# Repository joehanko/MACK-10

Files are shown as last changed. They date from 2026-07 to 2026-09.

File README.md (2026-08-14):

# MACK-10 Tensile Tester

> An open-source desktop tensile tester for affordable material characterization and education.

<p align="center">
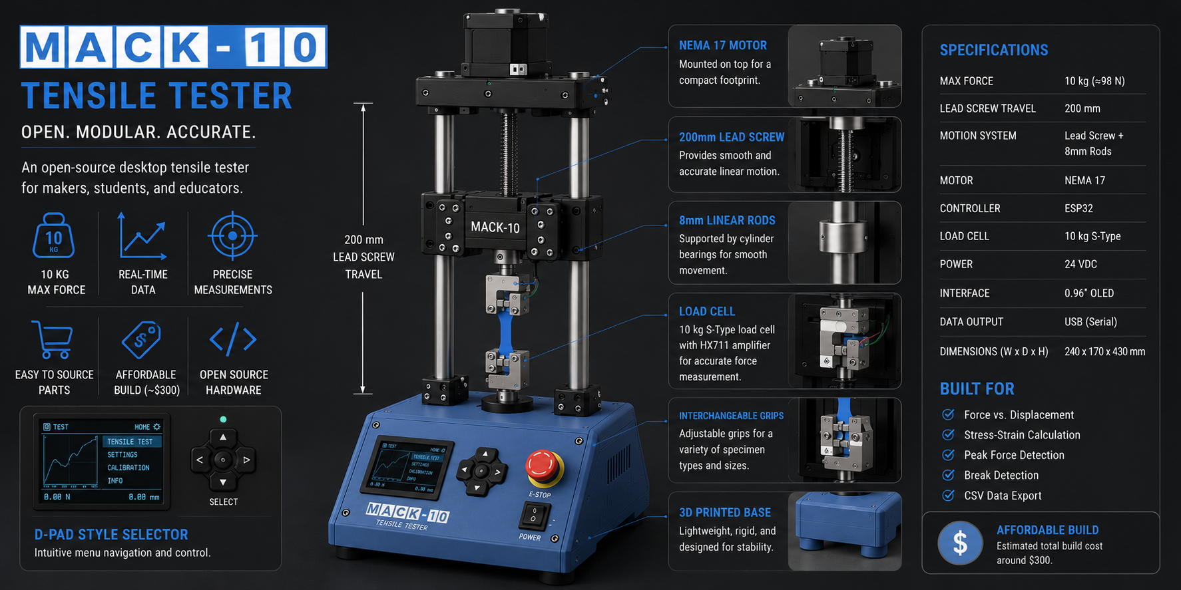
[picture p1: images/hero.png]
MACK-10 Banner
  
</p>






---

# Overview

MACK-10 is an open-source desktop tensile tester designed to measure the force and displacement of small material specimens.

The project combines an ESP32-based controller, load cell, stepper-driven linear stage, custom PCB, and 3D-printed components to create a low-cost alternative to commercial material testing equipment.

The target capacity is **10 kg (~98 N)**, making MACK-10 suitable for testing:

- 3D-printed plastics
- Engineering polymers
- Composites
- Thin metals
- Educational material samples

---

# Current Status

🚧 **Prototype Development — Revision 1**

<p align="center">
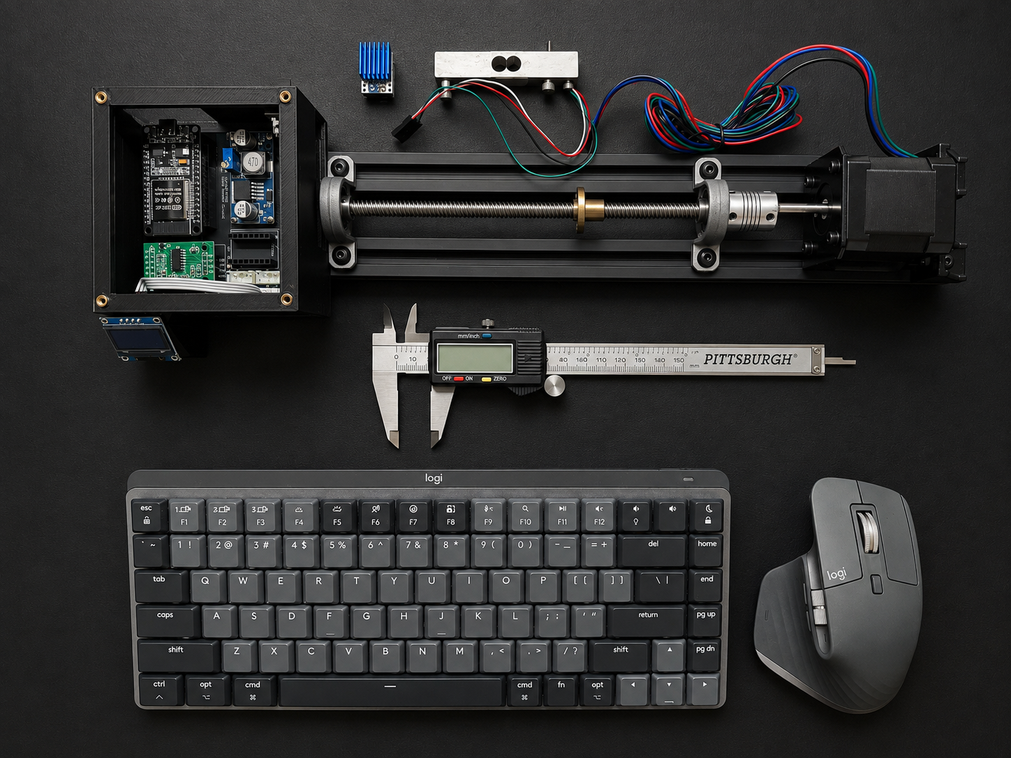
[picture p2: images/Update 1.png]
  
</p>

## Electronics

<p align="center">
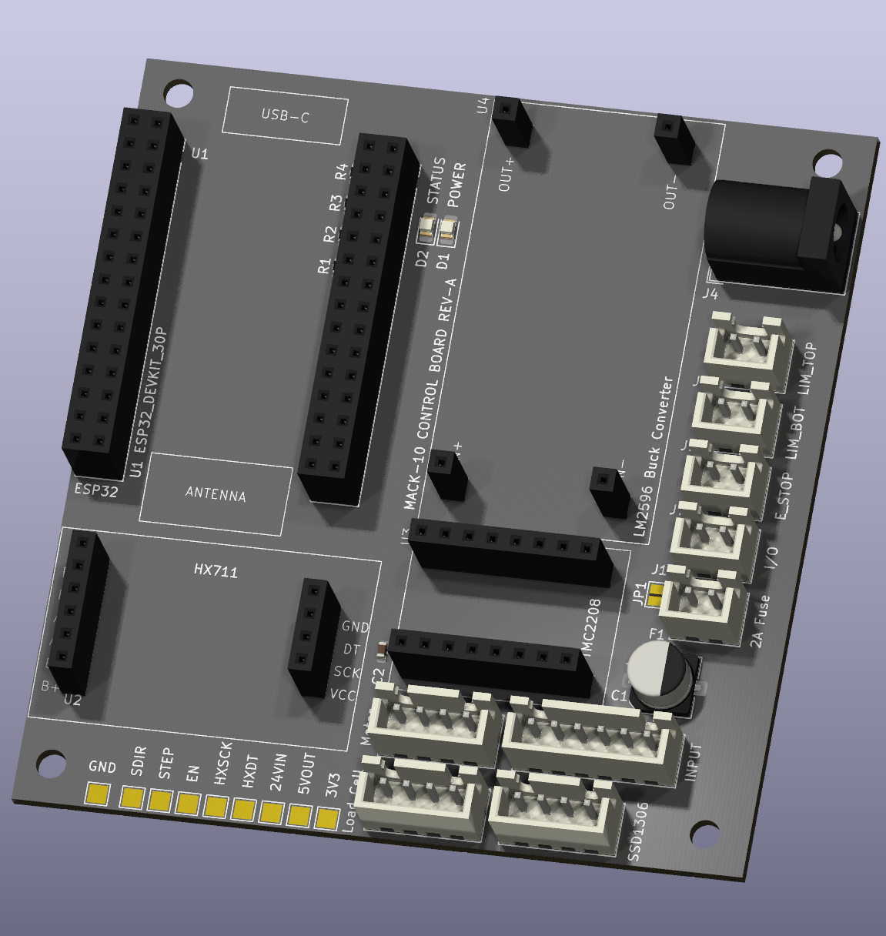
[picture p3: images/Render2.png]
MACK-10 PCB Render
  
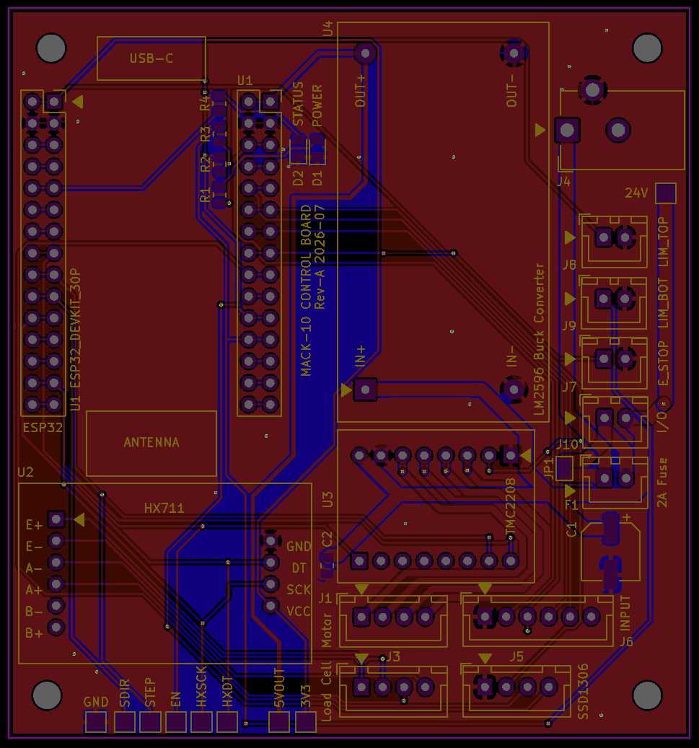
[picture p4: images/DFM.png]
MACK-10 PCB
  
</p>

- [x] Custom KiCad controller PCB
- [x] ESP32 controller
- [x] HX711 load cell interface
- [x] TMC2208 stepper driver
- [x] LM2596 power regulation
- [x] OLED interface
- [x] E-stop input
- [x] Dual limit switch inputs
- [x] PlatformIO firmware
- [x] Automatic taring
- [x] Peak force tracking
- [x] Break detection
- [x] Live serial plotting

## Mechanical

- [x] 200 mm T6×1 linear motion stage
- [x] NEMA 11 stepper drive
- [ ] Structural frame
- [ ] Load cell mount
- [ ] Specimen grips
- [ ] Electronics enclosure

## In Development

- [ ] Load cell calibration
- [ ] Crosshead speed control
- [ ] Position tracking
- [ ] Force-displacement logging
- [ ] Stress-strain calculations
- [ ] CSV export

---

# Target Specifications

| Specification  | Target |
| --- | --- |
| Maximum Force  | 10 kg (~98 N) |
| Load Cell | 10 kg S-Type |
| Controller | ESP32 |
| Motion | NEMA 11 + T6×1 Lead Screw |
| Travel | 200 mm |
| User Interface | 128×64 OLED |
| PCB | Custom KiCad Design |
| Firmware | PlatformIO |

---

# Bill of Materials

## Electronics

| Qty | Component | Approx. Cost | Line Total |
| ----: | --- | ---: | ---: |
| 1 | ESP32 DevKit V1 | $8.00 | $8.00 |
| 1 | Custom MACK-10 Controller PCB | $1.08 | $1.08 |
| 1 | HX711 Load Cell Amplifier | $3.00 | $3.00 |
| 1 | TMC2208 Stepper Driver | $5.00 | $5.00 |
| 1 | LM2596 Buck Converter | $2.00 | $2.00 |
| 1 | 10 kg S-Type Load Cell | $25.00 | $25.00 |
| 1 | SSD1306 128×64 OLED | $5.00 | $5.00 |
| 1 | PCB Fuse Holder | $1.00 | $1.00 |
| 1 | 2–2.5 A Fuse | $0.50 | $0.50 |
| 1 | Power Switch | $3.00 | $3.00 |
| 1 | Emergency Stop Switch | $12.00 | $12.00 |
| 2 | Limit Switches | $2.00 | $4.00 |
| 1 Set | JST-XH Connectors & Crimps | $4.00 | $4.00 |
| 1 Set | Female Header Sockets | $2.00 | $2.00 |
| — | LEDs, Resistors & Capacitors  | ~$2.00 | ~$2.00 |
| — | Wire, Heat Shrink & Misc. | ~$5.00 | ~$5.00 |

**Estimated Electronics Cost: ~$83**

## Mechanical

| Qty | Component | Approx. Cost | Line Total |
| --: | --- | ---: | ---: |
| 1 | T6×1 Linear Motion Stage, 200 mm | $31.99 | $31.99 |
| 1 | NEMA 11 Stepper Motor | Included | Included |
| 1 | T6×1 Lead Screw | Included | Included |
| 1 | Linear Guide & Carriage | Included | Included |
| 1 | Structural Frame Hardware | ~$20.00 | ~$20.00 |
| 1 | Grip Hardware | ~$20.00 | ~$20.00 |
| 1 | M3 Fastener Kit | ~$10.00 | ~$10.00 |
| 1 | M3 Heat-Set Inserts | ~$5.00 | ~$5.00 |
| — | Filament | ~$20.00 | ~$20.00 |

**Estimated Mechanical Cost: ~$107**

**Current Estimated Build Cost: ~$190 + power supply and miscellaneous hardware**

---

<p align="center">
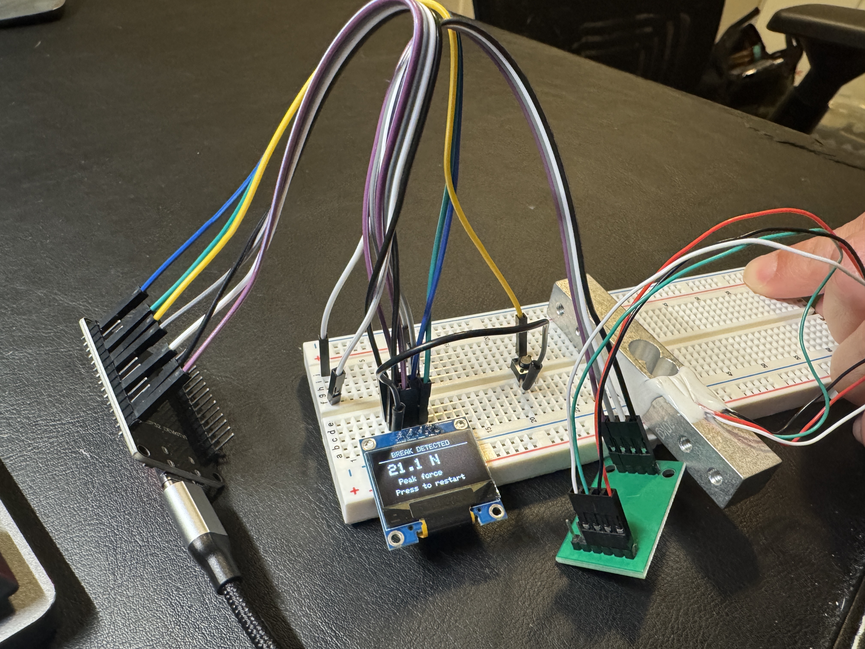
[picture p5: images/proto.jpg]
  
</p>

---

# Repository Structure

```text
firmware/    ESP32 firmware
pcb/         KiCad project files
cad/         Mechanical CAD models
docs/        Documentation
images/      Project photos and diagrams
```

---

# Roadmap

### Revision 1

Complete the mechanical assembly, calibrate the load cell, and perform initial tensile tests.

### Revision 2

Optimize the PCB, wiring, enclosure, motion control, and data acquisition.

### Revision 3

Add automated testing, material property calculations, and desktop software.

---

# Disclaimer

MACK-10 is intended for educational and hobby use and is not a replacement for calibrated or certified laboratory testing equipment.

Measurements should not be used for engineering certification, regulatory compliance, or safety-critical design decisions.

---

**Project Status:** Active Development 🚧

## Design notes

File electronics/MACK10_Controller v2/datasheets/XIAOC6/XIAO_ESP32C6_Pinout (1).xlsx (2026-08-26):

Table 7-2. QFN32 Package Pin Summary
管脚 序号 | 管脚 名称 | 管脚 类型 | 供电 管脚 | 管脚配置 |  | 模拟功能 |  | LP IO MUX 功能 |  | IO MUX 功能 |  |  |  |  |  |  | JTAG | USB | USER LED | LP IO MUX | BOOT
 |  |  |  | 复位时 | 复位后 | 0 | 1 | 0 | 1 | 0 | 类型 | 1 | 类型 | 2 | 类型 |  | GPIO | SDIO | Digital | Analog | IIC
1 | ANT | Analog |  |  |  |  |  |  |  |  |  |  |  |  |  |  | UART | SPI | ALL PWM | ALL I2S
2 | VDDA3P3 | Power
3 | VDDA3P3 | Power
4 | CHIP_PU | Analog |  |  |  |  |  |  |  |  |  |  |  |  |  |  | definition foot | multiplex
5 | VDDPST1 | Power
6 | XTAL_32K_P | IO | VDDPST1 |  |  | XTAL_32K_P | ADC1_CH0 | LP_GPIO0 | LP_UART_DTRN | GPIO0 | I/O/T | GPIO0 | I/O/T |  |  |  | D0 | A0 | GPIO0 | LP_GPIO0 | LP_UART_DTRN
7 | XTAL_32K_N | IO | VDDPST1 |  |  | XTAL_32K_N | ADC1_CH1 | LP_GPIO1 | LP_UART_DSRN | GPIO1 | I/O/T | GPIO1 | I/O/T |  |  |  | D1 | A1 | GPIO1 | LP_GPIO1 | LP_UART_DSRN
8 | GPIO2 | IO | VDDPST1 | IE | IE |  | ADC1_CH2 | LP_GPIO2 | LP_UART_RTSN | GPIO2 | I/O/T | GPIO2 | I/O/T | FSPIQ | I1/O/T |  | D2 | A2 | GPIO2 | LP_GPIO2 | LP_UART_RTSN
9 | GPIO3 | IO | VDDPST1 | IE | IE |  | ADC1_CH3 | LP_GPIO3 | LP_UART_CTSN | GPIO3 | I/O/T | GPIO3 | I/O/T |  |  |  | D11 | A3 | GPIO3 | LP_GPIO3 | LP_UART_CTSN
10 | MTMS | IO | VDDPST1 | IE | IE |  | ADC1_CH4 | LP_GPIO4 | LP_UART_RXD | MTMS | I1 | GPIO4 | I/O/T | FSPIHD | I1/O/T |  | MTMS | A4 | GPIO4 | LP_GPIO4 | LP_UART_RXD
11 | MTDI | IO | VDDPST1 | IE | IE |  | ADC1_CH5 | LP_GPIO5 | LP_UART_TXD | MTDI | I1 | GPIO5 | I/O/T | FSPIWP | I1/O/T |  | MTDI | A5 | GPIO5 | LP_GPIO5 | LP_UART_TXD
12 | MTCK | IO | VDDPST1 |  | IE, WPU |  | ADC1_CH6 | LP_GPIO6 | LP_I2C_SDA | MTCK | I1 | GPIO6 | I/O/T | FSPICLK | I1/O/T |  | MTCK | A6 | GPIO6 | LP_GPIO6 | LP_I2C_SDA
13 | MTDO | IO | VDDPST1 |  | IE |  |  | LP_GPIO7 | LP_I2C_SCL | MTDO | O/T | GPIO7 | I/O/T | FSPID | I1/O/T |  | MTDO |  | GPIO7 | LP_GPIO7 | LP_I2C_SCL
14 | GPIO8 | IO | VDDPST2 | IE | IE |  |  |  |  | GPIO8 | I/O/T | GPIO8 | I/O/T
15 | GPIO9 | IO | VDDPST2 | IE, WPU | IE, WPU |  |  |  |  | GPIO9 | I/O/T | GPIO9 | I/O/T |  |  |  | BOOT
16 | GPIO12 | IO | VDDPST2 |  | IE | USB_D- |  |  |  | GPIO12 | I/O/T | GPIO12 | I/O/T |  |  |  | USB_D-
17 | GPIO13 | IO | VDDPST2 |  | IE, WPU | USB_D+ |  |  |  | GPIO13 | I/O/T | GPIO13 | I/O/T |  |  |  | USB_D+
18 | GPIO14 | IO | VDDPST2 |  | IE |  |  |  |  | GPIO14 | I/O/T | GPIO14 | I/O/T |  |  |  | RF Switch
19 | GPIO15 | IO | VDDPST2 | IE | IE |  |  |  |  | GPIO15 | I/O/T | GPIO15 | I/O/T |  |  |  | USER LED
20 | VDDPST2 | Power
21 | U0TXD | IO | VDDPST2 |  | WPU |  |  |  |  | U0TXD | O | GPIO16 | I/O/T | FSPICS0 | I1/O/T |  | D6 | TX | GPIO16
22 | U0RXD | IO | VDDPST2 |  | IE, WPU |  |  |  |  | U0RXD | I1 | GPIO17 | I/O/T | FSPICS1 | O/T |  | D7 | RX | GPIO17
23 | SDIO_CMD | IO | VDDPST2 | WPU | IE |  |  |  |  | SDIO_CMD | I1/O/T | GPIO18 | I/O/T | FSPICS2 | O/T |  | D10 | MOSI | GPIO18 | SDIO_CMD
24 | SDIO_CLK | IO | VDDPST2 | WPU | IE |  |  |  |  | SDIO_CLK | I1 | GPIO19 | I/O/T | FSPICS3 | O/T |  | D8 | SCK | GPIO19 | SDIO_CLK
25 | SDIO_DATA0 | IO | VDDPST2 | WPU | IE |  |  |  |  | SDIO_DATA0 | I1/O/T | GPIO20 | I/O/T | FSPICS4 | O/T |  | D9 | MISO | GPIO20 | SDIO_DATA0
26 | SDIO_DATA1 | IO | VDDPST2 | WPU | IE |  |  |  |  | SDIO_DATA1 | I1/O/T | GPIO21 | I/O/T | FSPICS5 | O/T |  | D3 |  | GPIO21 | SDIO_DATA1
27 | SDIO_DATA2 | IO | VDDPST2 | WPU | IE |  |  |  |  | SDIO_DATA2 | I1/O/T | GPIO22 | I/O/T |  |  |  | D4 | SDA | GPIO22 | SDIO_DATA2
28 | SDIO_DATA3 | IO | VDDPST2 | WPU | IE |  |  |  |  | SDIO_DATA3 | I1/O/T | GPIO23 | I/O/T |  |  |  | D5 | SCL | GPIO23 | SDIO_DATA3
29 | VDDA1 | Power
30 | XTAL_N | Analog
31 | XTAL_P | Analog
32 | VDDA2 | Power
33 | GND | Power
ESP32C6FN4-QFN32 Package Pinout Overview
管脚 序号 | 管脚 名称 | 管脚 类型 1 | 供电 管脚 3-5 | 管脚配置 6,7 |  | 管脚功能 1,2
 |  |  |  | 复位时 | 复位后 | IO MUX | LP IO MUX | 模拟
1 | ANT | 模拟
2 | VDDA3P3 | 电源
3 | VDDA3P3 | 电源 |  |  |  |  |  |  | Table 2-4. QFN32 IO MUX Pin Functions
4 | CHIP_PU | 模拟 | VDDPST1 |  |  |  |  |  | 管脚 序号 | IO MUX / GPIO 名称 | IO MUX 功能
5 | VDDPST1 | 电源 |  |  |  |  |  |  |  |  | 0 | 类型 | 1 | 类型 | 2 | 类型
6 | XTAL_32K_P | IO | VDDPST1 |  |  | IO MUX | LP IO MUX | Analog | 6 | GPIO0 | GPIO0 | I/O/T | GPIO0 | I/O/T
7 | XTAL_32K_N | IO | VDDPST1 |  |  | IO MUX | LP IO MUX | Analog | 7 | GPIO1 | GPIO1 | I/O/T | GPIO1 | I/O/T
8 | GPIO2 | IO | VDDPST1 | IE | IE | IO MUX | LP IO MUX | Analog | 8 | GPIO2 | GPIO2 | I/O/T | GPIO2 | I/O/T | FSPIQ | I1/O/T
9 | GPIO3 | IO | VDDPST1 | IE | IE | IO MUX | LP IO MUX | Analog | 9 | GPIO3 | GPIO3 | I/O/T | GPIO3 | I/O/T
10 | MTMS | IO | VDDPST1 | IE | IE | IO MUX | LP IO MUX | Analog | 10 | GPIO4 | MTMS | I1 | GPIO4 | I/O/T | FSPIHD | I1/O/T
11 | MTDI | IO | VDDPST1 | IE | IE | IO MUX | LP IO MUX | Analog | 11 | GPIO5 | MTDI | I1 | GPIO5 | I/O/T | FSPIWP | I1/O/T
12 | MTCK | IO | VDDPST1 |  | IE, WPU 6 | IO MUX | LP IO MUX | Analog | 12 | GPIO6 | MTCK | I1 | GPIO6 | I/O/T | FSPICLK | I1/O/T
13 | MTDO | IO | VDDPST1 |  | IE | IO MUX | LP IO MUX |  | 13 | GPIO7 | MTDO | O/T | GPIO7 | I/O/T | FSPID | I1/O/T
14 | GPIO8 | IO | VDDPST2 | IE | IE | IO MUX |  |  | 14 | GPIO8 | GPIO8 | I/O/T | GPIO8 | I/O/T
15 | GPIO9 | IO | VDDPST2 | IE, WPU | IE, WPU | IO MUX |  |  | 15 | GPIO9 | GPIO9 | I/O/T | GPIO9 | I/O/T
16 | GPIO12 | IO | VDDPST2 |  | IE | IO MUX |  | Analog | 16 | GPIO12 | GPIO12 | I/O/T | GPIO12 | I/O/T
17 | GPIO13 | IO | VDDPST2 | USB_PU | IE, USB_PU | IO MUX |  | Analog | 17 | GPIO13 | GPIO13 | I/O/T | GPIO13 | I/O/T
18 | GPIO14 | IO | VDDPST2 |  | IE | IO MUX |  |  | 18 | GPIO14 | GPIO14 | I/O/T | GPIO14 | I/O/T
19 | GPIO15 | IO | VDDPST2 | IE | IE | IO MUX |  |  | 19 | GPIO15 | GPIO15 5b | I/O/T | GPIO15 | I/O/T
20 | VDDPST2 | 电源
21 | U0TXD | IO | VDDPST2 |  | WPU 7 | IO MUX |  |  | 21 | GPIO16 | U0TXD | O | GPIO16 | I/O/T | FSPICS0 | I1/O/T
22 | U0RXD | IO | VDDPST2 |  | IE, WPU | IO MUX |  |  | 22 | GPIO17 | U0RXD | I1 | GPIO17 | I/O/T | FSPICS1 | O/T
23 | SDIO_CMD | IO | VDDPST2 | WPU | IE | IO MUX |  |  | 23 | GPIO18 | SDIO_CMD | I1/O/T | GPIO18 | I/O/T | FSPICS2 | O/T
24 | SDIO_CLK | IO | VDDPST2 | WPU | IE | IO MUX |  |  | 24 | GPIO19 | SDIO_CLK | I1 | GPIO19 | I/O/T | FSPICS3 | O/T
25 | SDIO_DATA0 | IO | VDDPST2 | WPU | IE | IO MUX |  |  | 25 | GPIO20 | SDIO_DATA0 | I1/O/T | GPIO20 | I/O/T | FSPICS4 | O/T
26 | SDIO_DATA1 | IO | VDDPST2 | WPU | IE | IO MUX |  |  | 26 | GPIO21 | SDIO_DATA1 | I1/O/T | GPIO21 | I/O/T | FSPICS5 | O/T
27 | SDIO_DATA2 | IO | VDDPST2 | WPU | IE | IO MUX |  |  | 27 | GPIO22 | SDIO_DATA2 | I1/O/T | GPIO22 | I/O/T
28 | SDIO_DATA3 | IO | VDDPST2 | WPU | IE | IO MUX |  |  | 28 | GPIO23 | SDIO_DATA3 | I1/O/T | GPIO23 | I/O/T
29 | VDDA1 | 电源
30 | XTAL_N | 模拟
31 | XTAL_P | 模拟
32 | VDDA2 | 电源
33 | GND | 电源

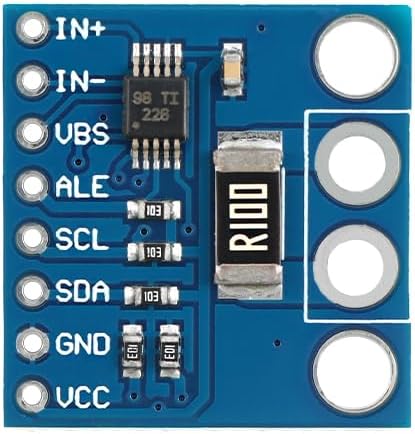
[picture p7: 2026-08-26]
electronics/MACK10_Controller v2/datasheets/INA226/51yJgzm+eNL._AC_SX679_.jpg

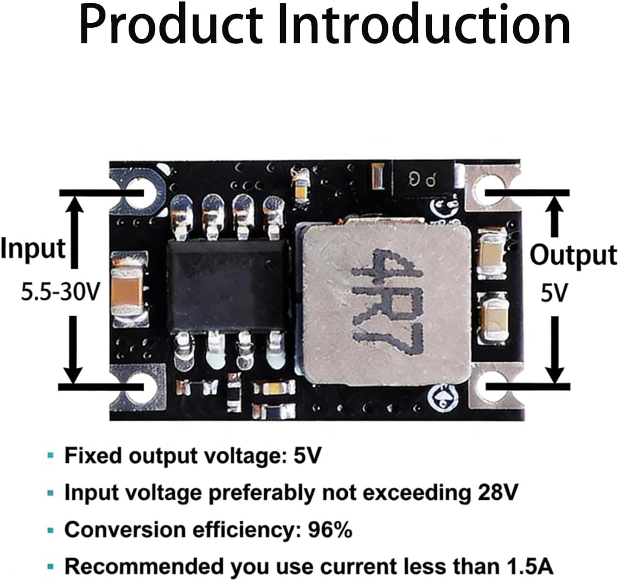
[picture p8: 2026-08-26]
electronics/MACK10_Controller v2/datasheets/Mini360/61MHXfFIcaL._AC_SL1200_.jpg

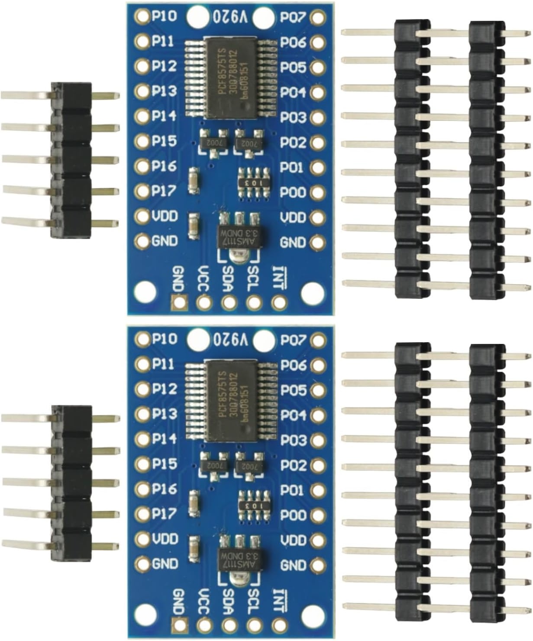
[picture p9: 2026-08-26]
electronics/MACK10_Controller v2/datasheets/PCF8575/71X1JMmVFlL._AC_SL1500_.jpg

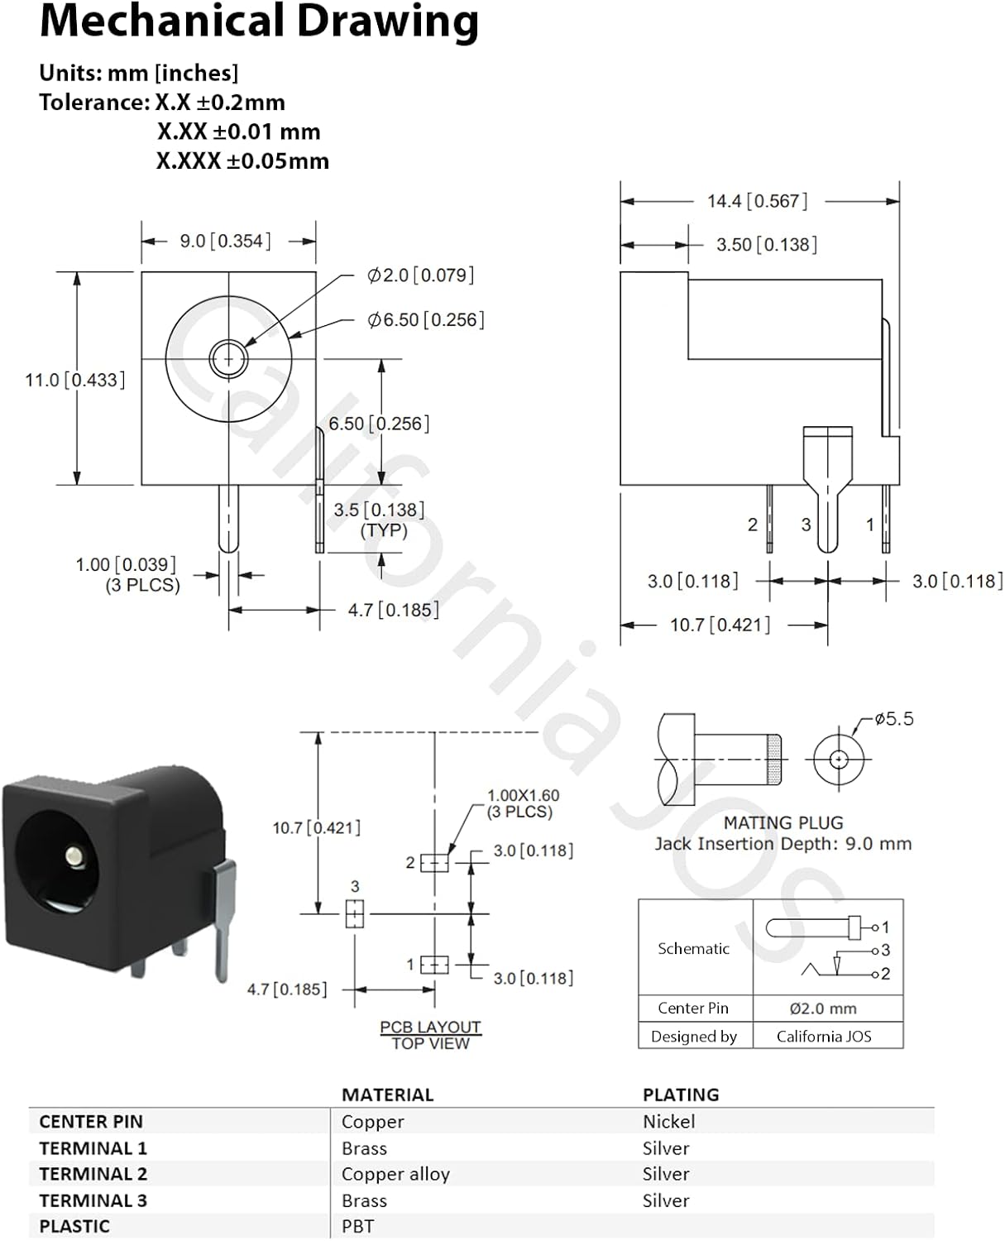
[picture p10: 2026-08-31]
electronics/MACK10_Controller v2/datasheets/DC Barrel Plug/61fno5+TJOL._AC_SL1500_.jpg

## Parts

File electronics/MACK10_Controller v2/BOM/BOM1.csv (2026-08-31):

Reference | Qty | Value | DNP | Exclude from BOM | Exclude from Board | Footprint | Datasheet
C1,C4,C6,C8 | 4 | 0.1uF |  |  |  | Capacitor_SMD:C_0805_2012Metric
C2,C3 | 2 | 10uF |  |  |  | Capacitor_SMD:C_0805_2012Metric
C5 | 1 | 100nF 50V |  |  |  | Capacitor_SMD:C_0805_2012Metric
C7 | 1 | 100uF 35V |  |  |  | Capacitor_SMD:CP_Elec_6.3x7.7
D1 | 1 | POWER |  |  |  | LED_SMD:LED_0805_2012Metric_Pad1.15x1.40mm_HandSolder
D2 | 1 | STATUS |  |  |  | LED_SMD:LED_0805_2012Metric_Pad1.15x1.40mm_HandSolder
D3 | 1 | SS14 |  |  |  | Diode_SMD:D_SMA | http://www.vishay.com/docs/88525/1n5817.pdf
F1 | 1 | Fuse |  |  |  | Connector_JST:JST_XH_B2B-XH-A_1x02_P2.50mm_Vertical
J2 | 1 | Motor |  |  |  | Connector_JST:JST_XH_B4B-XH-A_1x04_P2.50mm_Vertical
J3 | 1 | J_Expansion |  |  |  | Connector_PinHeader_2.54mm:PinHeader_2x07_P2.54mm_Vertical
J4 | 1 | I/O |  |  |  | Connector_JST:JST_XH_B2B-XH-A_1x02_P2.50mm_Vertical
J5 | 1 | Sensor IDC |  |  |  | Connector_IDC:IDC-Header_2x05_P2.54mm_Vertical
J6 | 1 | Interface IDC |  |  |  | Connector_IDC:IDC-Header_2x05_P2.54mm_Vertical
J7 | 1 | Fan |  |  |  | Connector_PinHeader_2.54mm:PinHeader_1x02_P2.54mm_Vertical
J8 | 1 | E_STOP |  |  |  | Connector_JST:JST_XH_B2B-XH-A_1x02_P2.50mm_Vertical
J9 | 1 | 24V IN |  |  |  | Connector_BarrelJack:BarrelJack_CUI_PJ-102AH_Horizontal
J10 | 1 | BYP_2 |  |  |  | Connector_PinHeader_2.54mm:PinHeader_1x02_P2.54mm_Vertical
JP1 | 1 | BYP_1 |  |  |  | Connector_PinHeader_2.54mm:PinHeader_1x02_P2.54mm_Vertical
Q1 | 1 | SS8550 |  |  |  | Package_TO_SOT_SMD:SOT-23 | http://www.secosgmbh.com/datasheet/products/SSMPTransistor/SOT-23/SS8550.pdf
R1,R2 | 2 | 100 |  |  |  | Resistor_SMD:R_0805_2012Metric
R3 | 1 | 18k |  |  |  | Resistor_SMD:R_0805_2012Metric
R4 | 1 | 7.5k |  |  |  | Resistor_SMD:R_0805_2012Metric
R5 | 1 | 470 |  |  |  | Resistor_SMD:R_0805_2012Metric
R6,R7 | 2 | 1k |  |  |  | Resistor_SMD:R_0805_2012Metric
R8,R9,R10,R13 | 4 | 10k |  |  |  | Resistor_SMD:R_0805_2012Metric
R11,R12 | 2 | 4.7k, DNP |  |  |  | Resistor_SMD:R_0805_2012Metric
SW1 | 1 | RESET |  |  |  | Button_Switch_SMD:SW_SPST_CK_RS282G05A3
TP1 | 1 | STEP |  |  |  | TestPoint:TestPoint_Pad_2.0x2.0mm
TP2 | 1 | HX_DT |  |  |  | TestPoint:TestPoint_Pad_2.0x2.0mm
TP3 | 1 | HX_SCK |  |  |  | TestPoint:TestPoint_Pad_2.0x2.0mm
TP4 | 1 | SDA |  |  |  | TestPoint:TestPoint_Pad_2.0x2.0mm
TP5 | 1 | SCL |  |  |  | TestPoint:TestPoint_Pad_2.0x2.0mm
TP6 | 1 | VMOT |  |  |  | TestPoint:TestPoint_Pad_2.0x2.0mm
TP7 | 1 | M24V |  |  |  | TestPoint:TestPoint_Pad_2.0x2.0mm
TP8 | 1 | 3V3 |  |  |  | TestPoint:TestPoint_Pad_2.0x2.0mm
TP9 | 1 | 24V |  |  |  | TestPoint:TestPoint_Pad_2.0x2.0mm
TP10 | 1 | 5VOUT |  |  |  | TestPoint:TestPoint_Pad_2.0x2.0mm
TP11 | 1 | GND |  |  |  | TestPoint:TestPoint_Pad_2.0x2.0mm
U1 | 1 | TMC2208 |  |  |  | MACK10:TMC2208_STEPSTICK
U2 | 1 | HX711 |  |  |  | Package_SO:SOIC-16_3.9x9.9mm_P1.27mm | https://web.archive.org/web/20220615044707/https://akizukidenshi.com/download/ds/avia/hx711.pdf
U3 | 1 | XIAO-C6 |  |  |  | XIAO-SEEDSTUDIO:XIAO-ESP32-C6-SMD
U4 | 1 | INA226 |  |  |  | MACK10:INA226
U5 | 1 | PCF8575 |  |  |  | MACK10:PCF8575
U6 | 1 | MINI360 |  |  |  | Mini360:Mini360_step-down

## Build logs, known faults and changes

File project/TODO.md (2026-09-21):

## MACK-10 TODO - V1

### Schematic

- [x] Finish ESP32 wiring
- [x] Finish limit switch circuitry
- [x] Verify all power nets
- [x] Add remaining test points
- [x] Run ERC with zero errors
- [x] Assign footprints

### PCB Layout

- [x] Update PCB from schematic
- [x] Connect duplicated ESP32 breakout pads (socket ↔ breakout header)
- [x] Place all components
- [x] Route power traces
- [x] Route signal traces
- [x] Add ground pours
- [x] Run DRC
- [x] Review silkscreen

### Prototype

- [x] Order Rev A PCBs
- [x] Assemble board
- [x] Test power rails
- [x] Program ESP32
- [x] Verify HX711
- [x] Verify stepper driver

## MACK-10 TODO - V2

### PCB Layout

- [ ] Move ESP32 Right Header 2.54mm x+, to ensure proper seat of ESP32
- [ ] Add test pins for current readings (FUSE)
- [ ] Integrate Buck Converter into board
- [ ] 24 and 9V Toggle Jumper ?
- [ ] I2C Interface Expansion Pins (4x16 GND, VCC, SCL, SDA)
- [ ] M3 Through-hole reinforcements / grounding
- [0] TMC2208 / TMC2209 90deg Header rotation for fan / cross ventilate
- [0] Buck Converter Header
- [0] Adjust Right ESP32 Header by 2.54mm
- [x] DC Jack Pin Correction (ground pin 2-3 swap)
- [x] Move DC and USB connections to same location
- [x] Swap out Fuse JST connector for jumper
- [x] Reduce board size (1/2)
- [x] Integrate HX711 into board
- [x] Fuse Pads (board perimeter) for solder jumper or pad connection
- [x] Voltage Testing Pins
- [x] Move TMC2208 Pin 1 Arrow to EN
- [x] Change Stepper Pin 1 Location (Enable)
- [x] Add 3 separate Status LEDs, multicolor? - RGB I2C Addressable
- [x] External Status LED
- [x] Inline Current Pins
- [x] Onboard Current Sensor IC
- [x] Add stepper Test Pins (Voltage and pin location)
- [x] Add flyback diode to prevent motor EMF
- [x] Add rotary encoder input pins
- [x] Switch to 2x5 ribbon cable male header for inputs
- [x] Change input pins to joystick (active, not signal)
- [x] Add more ground test pins
- [x] Add test pins to back of board (?)
- [x] Connect Unused Pins as Male Headers

## MACK-10 TODO - V3 Notes

- [ ] Ensure all GND are connected to GND plane / fill (2 unconnected GNDs)
- [ ] Some footprints clipped (too close to edge of board)
- [ ] VIN and GND test pins too close (risks short)
- [ ] Bypass pins could be a 2x3 vertical stack to save space (specialized pin header)
- [ ] Thermal relief checks
- [ ] Avoid via-in-pad wherever possible
- [ ]--- Make note of difficult to solder pins (thermal relief issues)
- [ ] Integrade PCF8575 / I/O expander to save space
- [ ] 4-layer board
- [ ] Pick-and-place small SMDs / resistors (move to 0603 or smaller)
- [ ] Pogo pins over test pads? Or external testing Pins to test board?
- [ ] INA226 Footprint wrong orientation, rotate 90º as board is too wide
- [ ] Move XIAO underneath EN Pad / hard to solder
- [ ] Smaller reset button
- [ ] Put I/0, Fuse, E-stop in one 1x6 connector
- [ ] Replace 50V Cap Electrolytic Can to SMD
- [ ] Expand MINI360 Pads outward for easier soldering

## Bring-up Checklist

- [] Finish enclosure
- [] Calibrate load cell properly in N
- [] Fix/finish INA226 current sensing
- [] Add E-stop logic + latched reset behavior
- [] Add limit switches
- [] Add magnetic encoder
- [] Add OLED/display UI
- [] Add physical buttons
- [] Add user-facing status LED
- [] Move firmware into PlatformIO
- [] Split firmware into modules (motor, loadcell, display, safety, web, etc.)
- [] Create automated Rev-B board self-test / bring-up routine
- [] Rebuild the tensile-test state machine cleanly
- [] Rebuild the XIAO-hosted web dashboard
- [] Keep the 15-second rolling live graph
- [] Keep full test history for CSV export
- [] Add Start / Stop / New Test browser controls
- [] Tie web test flow into motor + fracture detection
- [] Later add displacement, force-vs-displacement, stress/strain, and richer test exports

### Mechanical

- [ ] Design moving carriage
- [ ] Design uppper tensile gripper
- [ ] Design bottom stationary tensile gripper
- [ ] Design encoder mount

### Scripts

- [ ] Add multithreading I2C addressing
- [ ] Add Pin Expansion (reconfigurable)
- [ ] Startup test sequence
- [ ] Calibration sequence
- [ ] Rotary encoder input
- [ ] Estop shutdown signal and restart

### Instructions

- [ ] Quickstart Guide for board
  - [ ] Bring-up sequence: SMDs, Components, Headers, Buck trimpot test and glue, TMC2208 Vref Adjust:

1. Solder SMD components
2. Solder board components
3. Solder pin headers
4. Inspect solder joints
5. Check power shorts
6. Verify barrel input
7. Set buck 5V
8. Verify 3.3V rail
9. Install ESP32
10. Confirm serial boot
11. Install TMC2208
12. Set TMC2208 VREF
13. Verify OLED display
14. Verify HX711 readings
15. Connect load cell
16. Test control buttons
17. Test limit switches
18. Connect stepper motor
19. Test motor motion
20. Run full system

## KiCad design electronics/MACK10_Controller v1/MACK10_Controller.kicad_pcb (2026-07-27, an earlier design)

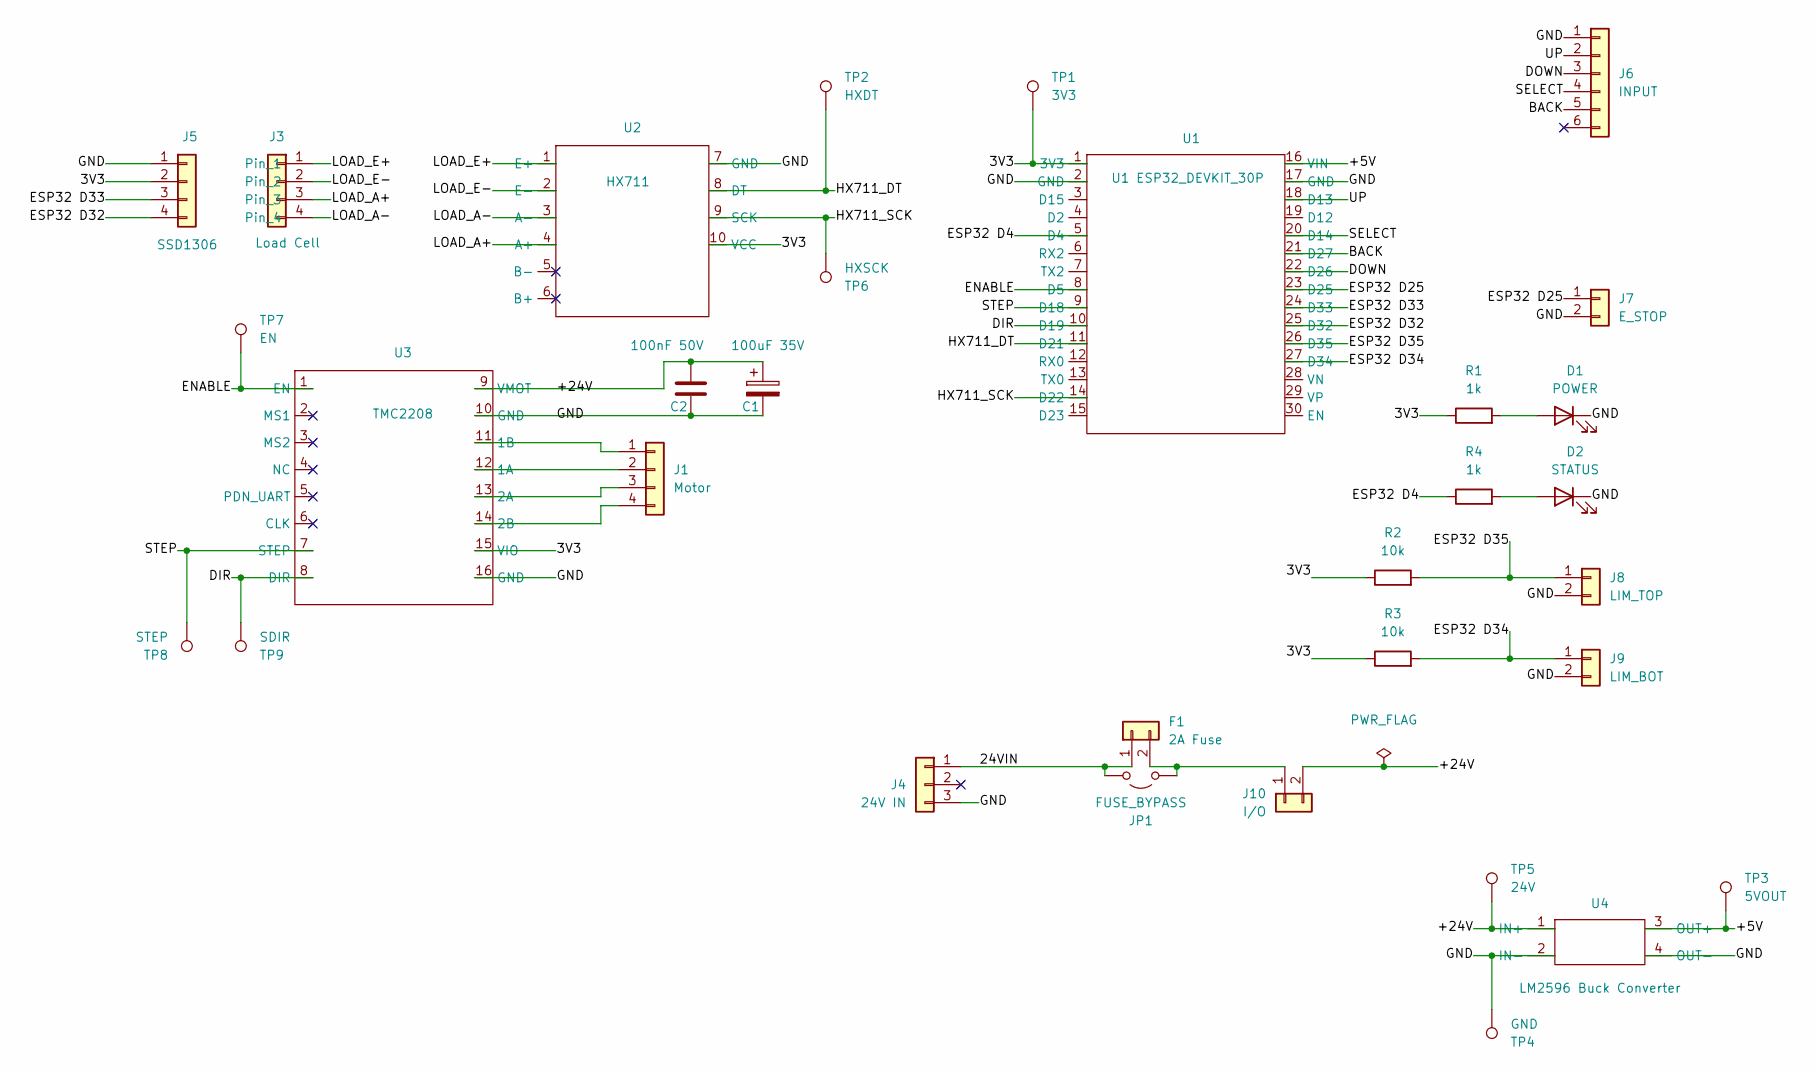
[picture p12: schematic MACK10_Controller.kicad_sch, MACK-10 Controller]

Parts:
C1: 100uF 35V; CP_Elec_6.3x7.7
C2: 100nF 50V; C_0805_2012Metric
D1: POWER; LED_0805_2012Metric_Pad1.15x1.40mm_HandSolder
D2: STATUS; LED_0805_2012Metric_Pad1.15x1.40mm_HandSolder
F1: 2A Fuse; JST_XH_B2B-XH-A_1x02_P2.50mm_Vertical
J1: Motor; JST_XH_B4B-XH-A_1x04_P2.50mm_Vertical
J3: Load Cell; JST_XH_B4B-XH-A_1x04_P2.50mm_Vertical
J4: 24V IN; BarrelJack_CUI_PJ-102AH_Horizontal
J5: SSD1306; JST_XH_B4B-XH-A_1x04_P2.50mm_Vertical
J6: INPUT; JST_XH_B6B-XH-A_1x06_P2.50mm_Vertical
J7: E_STOP; JST_XH_B2B-XH-A_1x02_P2.50mm_Vertical
J8: LIM_TOP; JST_XH_B2B-XH-A_1x02_P2.50mm_Vertical
J9: LIM_BOT; JST_XH_B2B-XH-A_1x02_P2.50mm_Vertical
J10: I/O; JST_XH_B2B-XH-A_1x02_P2.50mm_Vertical
JP1: FUSE_BYPASS; SolderJumper-2_P1.3mm_Open_Pad1.0x1.5mm
R1, R4: 1k; R_0805_2012Metric
R2, R3: 10k; R_0805_2012Metric
TP1: 3V3; TestPoint_Pad_2.0x2.0mm
TP2: HXDT; TestPoint_Pad_2.0x2.0mm
TP3: 5VOUT; TestPoint_Pad_2.0x2.0mm
TP4: GND; TestPoint_Pad_2.0x2.0mm
TP5: 24V; TestPoint_Pad_2.0x2.0mm
TP6: HXSCK; TestPoint_Pad_2.0x2.0mm
TP7: EN; TestPoint_Pad_2.0x2.0mm
TP8: STEP; TestPoint_Pad_2.0x2.0mm
TP9: SDIR; TestPoint_Pad_2.0x2.0mm
U1: U1 ESP32_DEVKIT_30P; ESP32_DEVKIT_30PIN
U2: HX711; HX711_MODULE
U3: TMC2208; TMC2208_STEPSTICK
U4: LM2596 Buck Converter; LM2596_BUCK_CONVERTER

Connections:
/3V3: J5.2, R1.1, R2.1, R3.1, TP1.1 (1_1), U1.1 (3V3), U2.10 (VCC), U3.15 (VIO)
/24VIN: F1.1, J4.1, JP1.1 (A)
/+5V: TP3.1 (1_1), U1.16 (VIN), U4.3 (OUT+)
/+24V: C1.1, C2.1, J10.2, TP5.1 (1_1), U3.9 (VMOT), U4.1 (IN+)
/BACK: J6.5, U1.21 (D27)
/DIR: TP9.1 (1_1), U1.10 (D19), U3.8 (DIR)
/DOWN: J6.3, U1.22 (D26)
/ENABLE: TP7.1 (1_1), U1.8 (D5), U3.1 (EN)
/ESP32 D4: R4.1, U1.5 (D4)
/ESP32 D25: J7.1, U1.23 (D25)
/ESP32 D32: J5.4, U1.25 (D32)
/ESP32 D33: J5.3, U1.24 (D33)
/ESP32 D34: J9.1, R3.2, U1.27 (D34)
/ESP32 D35: J8.1, R2.2, U1.26 (D35)
/GND: C1.2, C2.2, D1.1 (K), D2.1 (K), J4.3, J5.1, J6.1, J7.2, J8.2, J9.2, TP4.1 (1_1), U1.2 (GND), U1.17 (GND), U2.7 (GND), U3.10 (GND), U3.16 (GND), U4.2 (IN-), U4.4 (OUT-)
/HX711_DT: TP2.1 (1_1), U1.11 (D21), U2.8 (DT)
/HX711_SCK: TP6.1 (1_1), U1.14 (D22), U2.9 (SCK)
/LOAD_A+: J3.3, U2.4 (A+)
/LOAD_A-: J3.4, U2.3 (A-)
/LOAD_E+: J3.1, U2.1 (E+)
/LOAD_E-: J3.2, U2.2 (E-)
/SELECT: J6.4, U1.20 (D14)
/STEP: TP8.1 (1_1), U1.9 (D18), U3.7 (STEP)
/UP: J6.2, U1.18 (D13)
unnamed: D1.2 (A), R1.2
unnamed: D2.2 (A), R4.2
unnamed: F1.2, J10.1, JP1.2 (B)
unnamed: J1.1, U3.11 (1B)
unnamed: J1.2, U3.12 (1A)
unnamed: J1.3, U3.13 (2A)
unnamed: J1.4, U3.14 (2B)

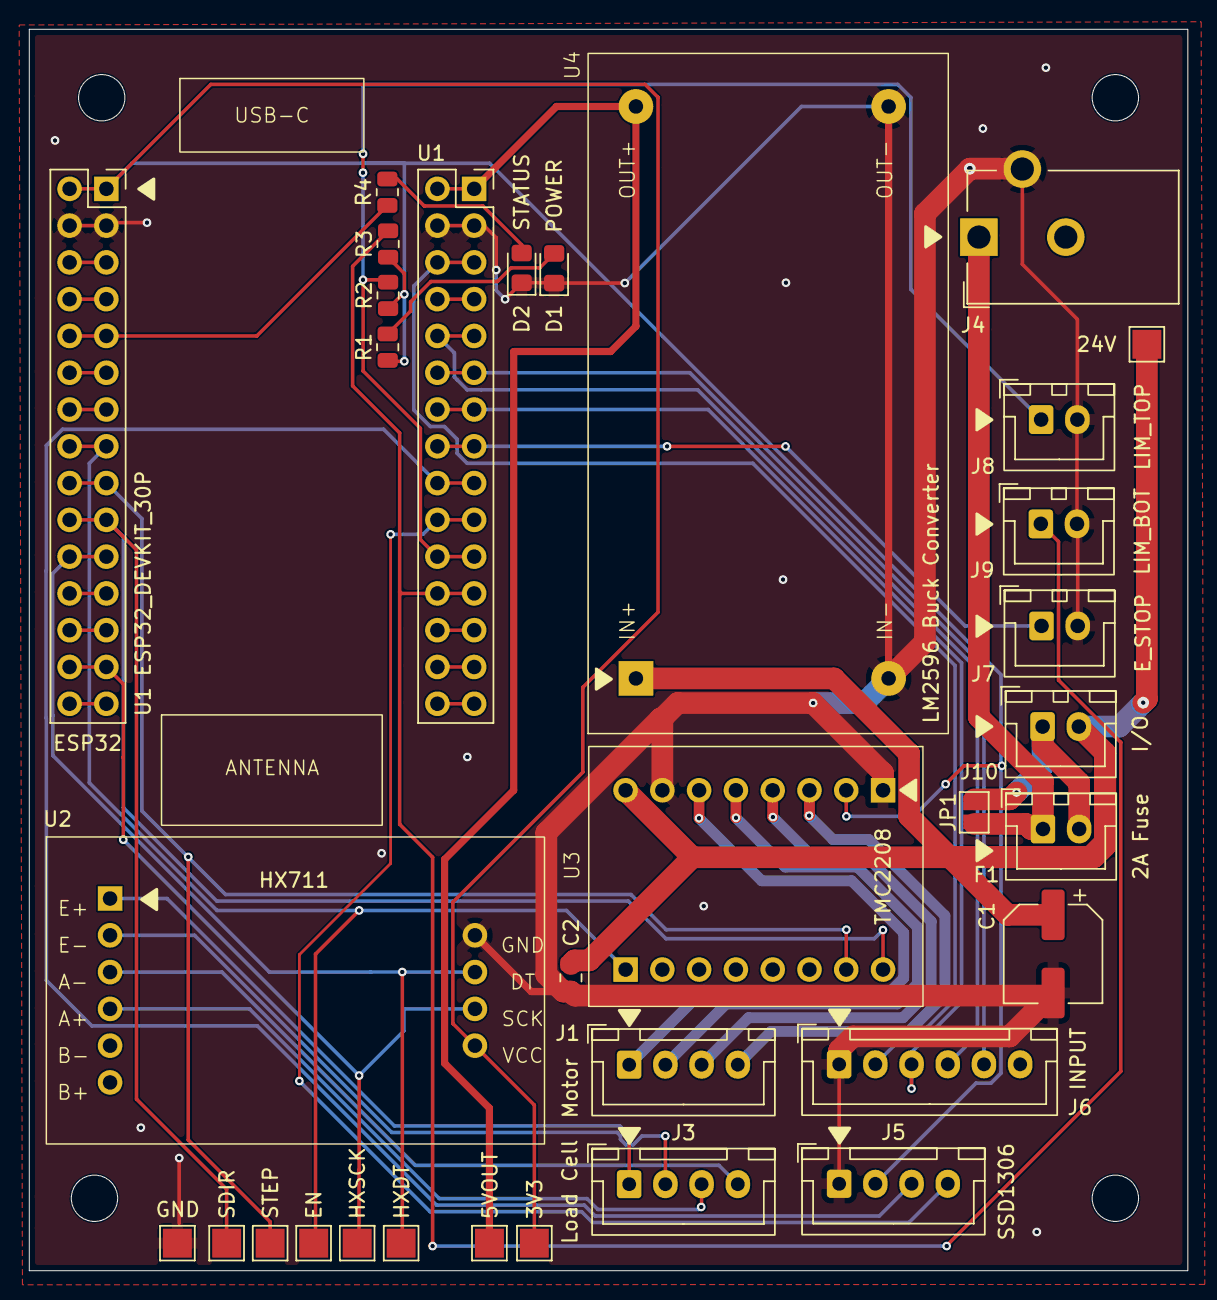
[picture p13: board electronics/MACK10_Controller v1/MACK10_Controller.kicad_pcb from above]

Board: 2 copper layers, 80.0 x 85.7 mm, 36 parts (0 on the bottom side), 31 nets.

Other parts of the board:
Mount 1, Mount 2, Mount 3, Mount 4: MountingHole_3.2mm_M3

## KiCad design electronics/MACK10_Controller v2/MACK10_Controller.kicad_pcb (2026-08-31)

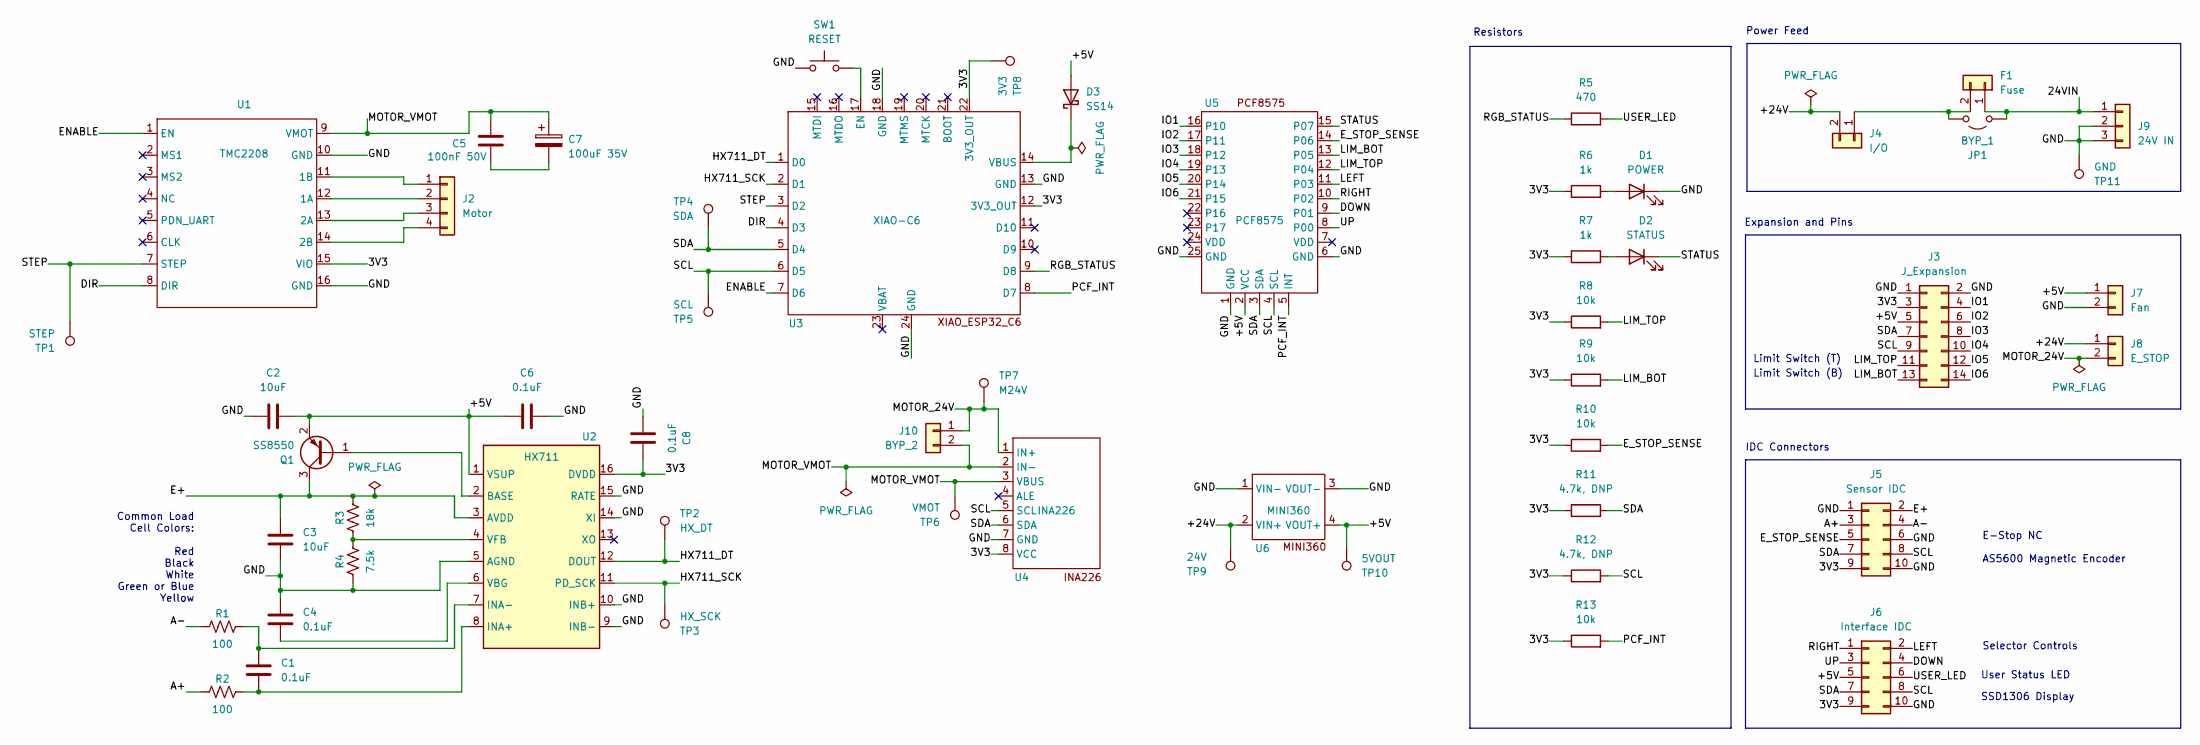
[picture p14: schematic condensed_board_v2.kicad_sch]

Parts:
C1, C4, C6, C8: 0.1uF; C_0805_2012Metric
C2, C3: 10uF; C_0805_2012Metric
C5: 100nF 50V; C_0805_2012Metric
C7: 100uF 35V; CP_Elec_6.3x7.7
D1: POWER; LED_0805_2012Metric_Pad1.15x1.40mm_HandSolder
D2: STATUS; LED_0805_2012Metric_Pad1.15x1.40mm_HandSolder
D3: SS14; D_SMA
F1: Fuse; JST_XH_B2B-XH-A_1x02_P2.50mm_Vertical
J2: Motor; JST_XH_B4B-XH-A_1x04_P2.50mm_Vertical
J3: J_Expansion; PinHeader_2x07_P2.54mm_Vertical
J4: I/O; JST_XH_B2B-XH-A_1x02_P2.50mm_Vertical
J5: Sensor IDC; IDC-Header_2x05_P2.54mm_Vertical
J6: Interface IDC; IDC-Header_2x05_P2.54mm_Vertical
J7: Fan; PinHeader_1x02_P2.54mm_Vertical
J8: E_STOP; JST_XH_B2B-XH-A_1x02_P2.50mm_Vertical
J9: 24V IN; BarrelJack_CUI_PJ-102AH_Horizontal
J10: BYP_2; PinHeader_1x02_P2.54mm_Vertical
JP1: BYP_1; PinHeader_1x02_P2.54mm_Vertical
Q1: SS8550; SOT-23
R1, R2: 100; R_0805_2012Metric
R3: 18k; R_0805_2012Metric
R4: 7.5k; R_0805_2012Metric
R5: 470; R_0805_2012Metric
R6, R7: 1k; R_0805_2012Metric
R8, R9, R10, R13: 10k; R_0805_2012Metric
R11, R12: 4.7k, DNP; R_0805_2012Metric
SW1: RESET; SW_SPST_CK_RS282G05A3
TP1: STEP; TestPoint_Pad_2.0x2.0mm
TP2: HX_DT; TestPoint_Pad_2.0x2.0mm
TP3: HX_SCK; TestPoint_Pad_2.0x2.0mm
TP4: SDA; TestPoint_Pad_2.0x2.0mm
TP5: SCL; TestPoint_Pad_2.0x2.0mm
TP6: VMOT; TestPoint_Pad_2.0x2.0mm
TP7: M24V; TestPoint_Pad_2.0x2.0mm
TP8: 3V3; TestPoint_Pad_2.0x2.0mm
TP9: 24V; TestPoint_Pad_2.0x2.0mm
TP10: 5VOUT; TestPoint_Pad_2.0x2.0mm
TP11: GND; TestPoint_Pad_2.0x2.0mm
U1: TMC2208; TMC2208_STEPSTICK
U2: HX711; SOIC-16_3.9x9.9mm_P1.27mm
U3: XIAO-C6; XIAO-ESP32-C6-SMD
U4: INA226
U5: PCF8575
U6: MINI360; Mini360_step-down

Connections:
/3V3: C8.1, J3.3, J5.9, J6.9, R6.1, R7.1, R8.1, R9.1, R10.1, R11.1, R12.1, R13.1, TP8.1 (1_1), U1.15 (VIO), U2.16 (DVDD), U3.12 (3V3_OUT), U3.22 (3V3_OUT), U4.8 (VCC); also elsewhere on the board
/24VIN: F1.1, J9.1, JP1.1 (A)
/+5V: C2.2, C6.1, D3.2 (A), J3.5, J6.5, J7.1, Q1.2 (E), TP10.1 (1_1), U2.1 (VSUP), U5.2 (VCC), U6.4 (VOUT+); also elsewhere on the board
/+24V: J4.2, J8.1, TP9.1 (1_1), U6.2 (VIN+)
/A+: J5.3, R2.1
/A-: J5.4, R1.1
/DIR: U1.8 (DIR), U3.4 (D3)
/DOWN: J6.4, U5.9 (P01)
/E+: C3.1, J5.2, Q1.3 (C), R3.2, U2.3 (AVDD)
/ENABLE: U1.1 (EN), U3.7 (D6)
/E_STOP_SENSE: J5.5, R10.2, U5.14 (P06)
/GND: C2.1, C3.2, C4.1, C6.2, C8.2, D1.1 (K), J3.1, J3.2, J5.1, J5.6, J5.10, J6.10, J7.2, J9.2, J9.3, R4.1, SW1.1, TP11.1 (1_1), U1.10 (GND), U1.16 (GND), U2.5 (AGND), U2.9 (INB-), U2.10 (INB+), U2.14 (XI), U2.15 (RATE), U3.13 (GND), U3.18 (GND), U3.24 (GND), U4.7 (GND), U5.1 (GND), U5.6 (GND), U5.25 (GND), U6.1 (VIN-), U6.3 (VOUT-)
/HX711_DT: TP2.1 (1_1), U2.12 (DOUT), U3.1 (D0)
/HX711_SCK: TP3.1 (1_1), U2.11 (PD_SCK), U3.2 (D1)
/IO1: J3.4, U5.16 (P10)
/IO2: J3.6, U5.17 (P11)
/IO3: J3.8, U5.18 (P12)
/IO4: J3.10, U5.19 (P13)
/IO5: J3.12, U5.20 (P14)
/IO6: J3.14, U5.21 (P15)
/LEFT: J6.2, U5.11 (P03)
/LIM_BOT: J3.13, R9.2, U5.13 (P05)
/LIM_TOP: J3.11, R8.2, U5.12 (P04)
/MOTOR_24V: J8.2, J10.1, TP7.1 (1_1), U4.1 (IN+)
/MOTOR_VMOT: C5.1, C7.1, J10.2, TP6.1 (1_1), U1.9 (VMOT), U4.2 (IN-), U4.3 (VBUS)
/PCF_INT: R13.2, U3.8 (D7), U5.5 (INT)
/RGB_STATUS: R5.1, U3.9 (D8)
/RIGHT: J6.1, U5.10 (P02)
/SCL: J3.9, J5.8, J6.8, R12.2, TP5.1 (1_1), U3.6 (D5), U4.5 (SCL), U5.4 (SCL)
/SDA: J3.7, J5.7, J6.7, R11.2, TP4.1 (1_1), U3.5 (D4), U4.6 (SDA), U5.3 (SDA)
/STATUS: D2.1 (K), U5.15 (P07)
/STEP: TP1.1 (1_1), U1.7 (STEP), U3.3 (D2)
/UP: J6.3, U5.8 (P00)
/USER_LED: J6.6, R5.2
unnamed: C5.2, C7.2
unnamed: D1.2 (A), R6.2
unnamed: D2.2 (A), R7.2
unnamed: D3.1 (K), U3.14 (VBUS)
unnamed: F1.2, J4.1, JP1.2 (B)
unnamed: J2.1, U1.11 (1B)
unnamed: J2.2, U1.12 (1A)
unnamed: J2.3, U1.13 (2A)
unnamed: J2.4, U1.14 (2B)
unnamed: Q1.1 (B), U2.2 (BASE)
unnamed: C1.2, R2.2, U2.8 (INA+)
unnamed: C1.1, R1.2, U2.7 (INA-)
unnamed: C4.2, U2.6 (VBG)
unnamed: R3.1, R4.2, U2.4 (VFB)
unnamed: SW1.2, U3.17 (EN)

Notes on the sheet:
Selector Controls
Limit Switch (T)
Power Feed
SSD1306 Display
Limit Switch (B)
Common Load Cell Colors: Red Black White Green or Blue Yellow
Resistors
User Status LED
Expansion and Pins
AS5600 Magnetic Encoder
IDC Connectors
E-Stop NC

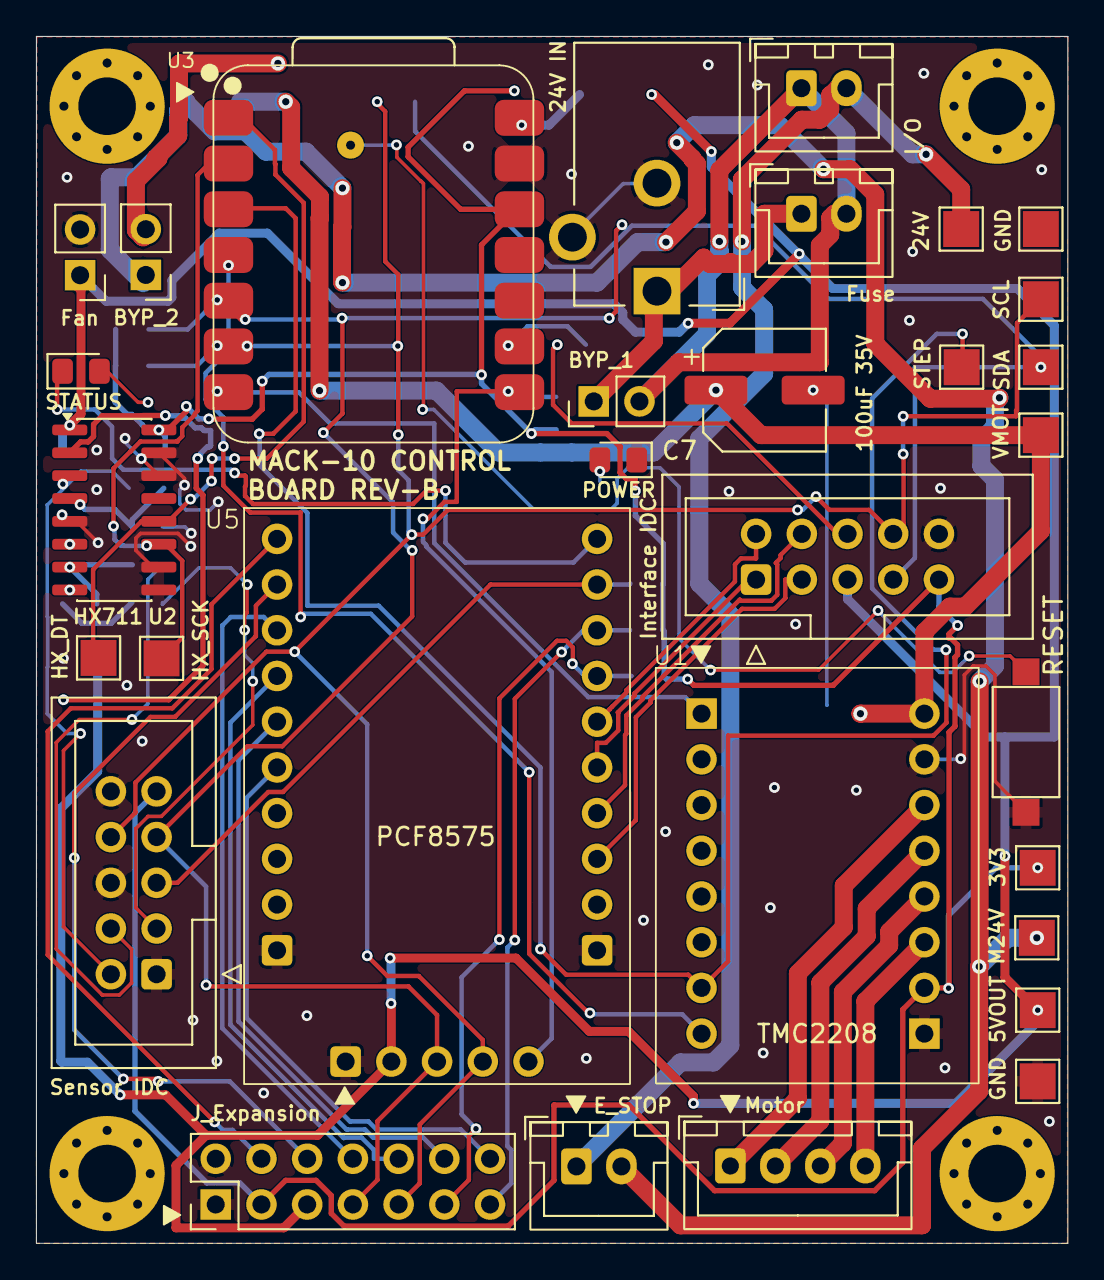
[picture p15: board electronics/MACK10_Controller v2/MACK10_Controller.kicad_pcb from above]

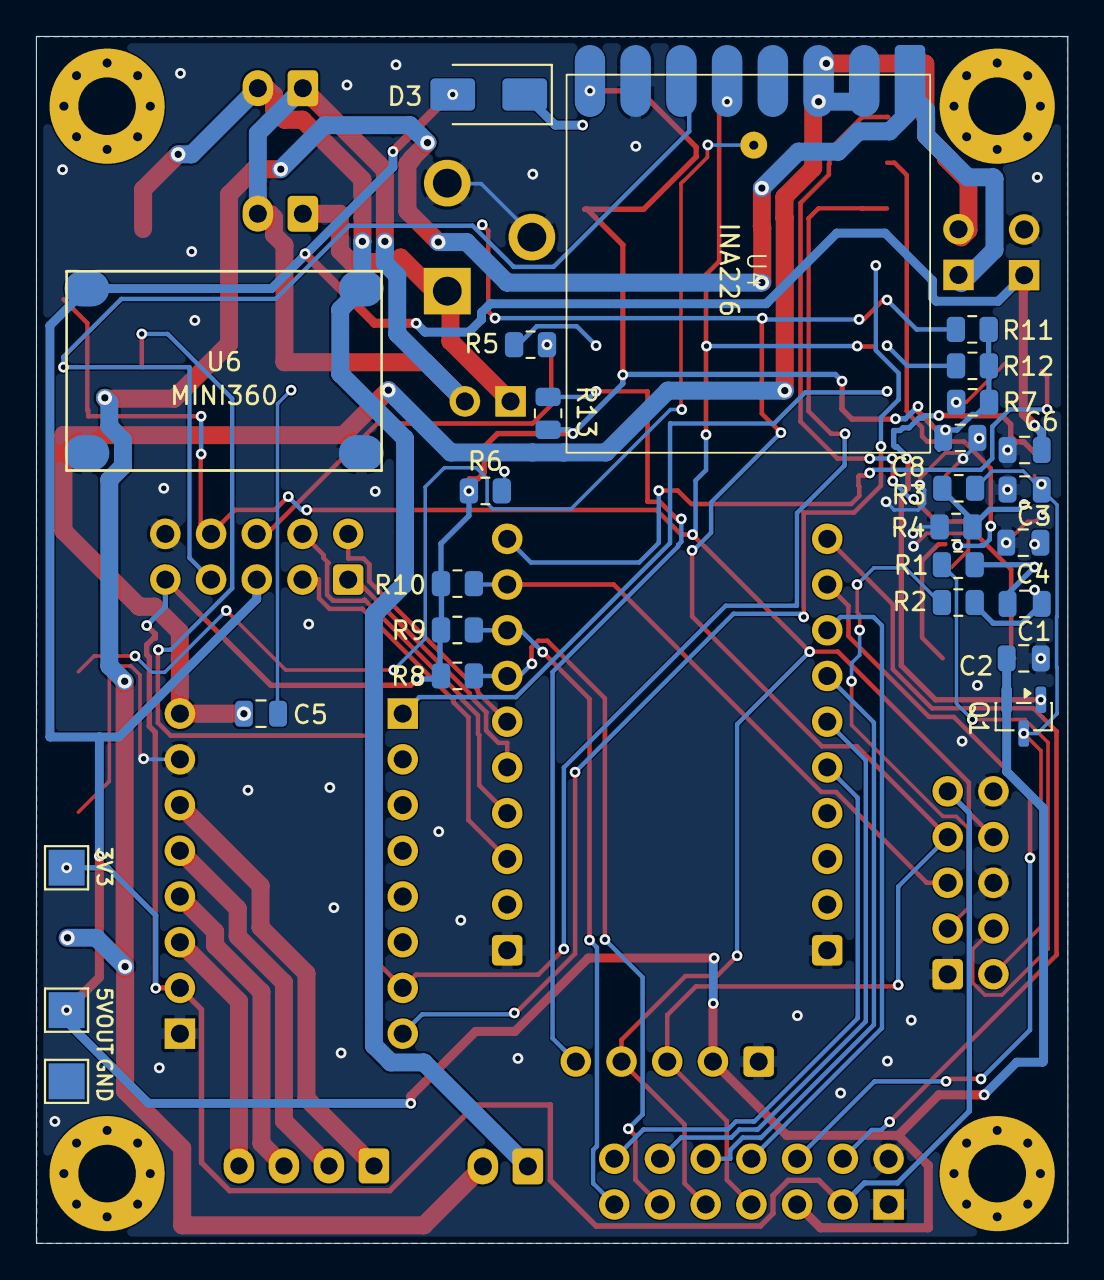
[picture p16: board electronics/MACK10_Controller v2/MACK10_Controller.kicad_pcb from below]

Board: 2 copper layers, 57.3 x 67.1 mm, 62 parts (27 on the bottom side), 49 nets.

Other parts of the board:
Mount 1, Mount 2, Mount 3, Mount 4: MountingHole_3.2mm_M3_Pad_Via
TP8#2: 3V3; TestPoint_Pad_2.0x2.0mm
TP10#2: 5VOUT; TestPoint_Pad_2.0x2.0mm
TP11#2, TP11#3: GND; TestPoint_Pad_2.0x2.0mm

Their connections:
/3V3: TP8#2.1 (1_1); also elsewhere on the board
/+5V: TP10#2.1 (1_1); also elsewhere on the board

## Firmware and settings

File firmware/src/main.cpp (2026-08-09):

#include <Adafruit_GFX.h>
#include <Adafruit_SSD1306.h>
#include <Arduino.h>
#include <Wire.h>

// =====================================================
// MACK-10 SMOOTH MOTOR + OLED TEST
// ESP32 Arduino Core 2.x
// TMC2208 hardware STEP generation with LEDC
// =====================================================

// =====================================================
// Pins
// =====================================================

constexpr int ENABLE_PIN = 5;
constexpr int STEP_PIN = 18;
constexpr int DIR_PIN = 19;

constexpr int OLED_SDA_PIN = 32;
constexpr int OLED_SCL_PIN = 33;

// =====================================================
// OLED
// =====================================================

constexpr int SCREEN_WIDTH = 128;
constexpr int SCREEN_HEIGHT = 64;
constexpr uint8_t OLED_ADDRESS = 0x3C;

Adafruit_SSD1306 display(
    SCREEN_WIDTH,
    SCREEN_HEIGHT,
    &Wire,
    -1);

// =====================================================
// Motion settings
// =====================================================

constexpr int START_STEP_HZ = 250;
constexpr int MAX_STEP_HZ = 2000;

constexpr unsigned long ACCEL_TIME_MS = 2500;
constexpr unsigned long CRUISE_TIME_MS = 3000;
constexpr unsigned long DECEL_TIME_MS = 2500;

constexpr unsigned long DIRECTION_PAUSE_MS = 1500;

// OLED refresh
constexpr unsigned long DISPLAY_INTERVAL_MS = 100;

// Update commanded motor frequency every 20 ms
constexpr unsigned long RAMP_UPDATE_INTERVAL_MS = 20;

// =====================================================
// ESP32 LEDC hardware STEP generator
// =====================================================

constexpr int STEP_CHANNEL = 0;
constexpr int STEP_RESOLUTION_BITS = 8;

// =====================================================
// Motion state
// =====================================================

enum MotionPhase
{
    WAITING,
    ACCELERATING,
    CRUISING,
    DECELERATING,
    PAUSED,
    COMPLETE
};

MotionPhase motionPhase = WAITING;

bool currentDirection = HIGH;

int currentStepHz = 0;

unsigned long phaseStartMs = 0;
unsigned long lastDisplayMs = 0;
unsigned long lastRampUpdateMs = 0;

// =====================================================
// Phase text
// =====================================================

const char *phaseName(MotionPhase phase)
{
    switch (phase)
    {
    case WAITING:
        return "WAITING";

    case ACCELERATING:
        return "ACCELERATING";

    case CRUISING:
        return "FULL SPEED";

    case DECELERATING:
        return "DECELERATING";

    case PAUSED:
        return "PAUSED";

    case COMPLETE:
        return "COMPLETE";
    }

    return "";
}

// =====================================================
// Hardware STEP control
// =====================================================

void startStepGenerator(int frequencyHz)
{
    if (frequencyHz < 1)
    {
        frequencyHz = 1;
    }

    currentStepHz = frequencyHz;

    // Hardware-generated square wave.
    ledcWriteTone(
        STEP_CHANNEL,
        frequencyHz);
}

void changeStepFrequency(int frequencyHz)
{
    if (frequencyHz < 1)
    {
        frequencyHz = 1;
    }

    currentStepHz = frequencyHz;

    ledcWriteTone(
        STEP_CHANNEL,
        frequencyHz);
}

void stopStepGenerator()
{
    currentStepHz = 0;

    ledcWriteTone(
        STEP_CHANNEL,
        0);

    ledcWrite(
        STEP_CHANNEL,
        0);
}

// =====================================================
// Progress bar
// =====================================================

void drawProgressBar(float progress)
{
    constexpr int BAR_X = 4;
    constexpr int BAR_Y = 50;
    constexpr int BAR_W = 120;
    constexpr int BAR_H = 10;

    progress =
        constrain(
            progress,
            0.0f,
            1.0f);

    display.drawRect(
        BAR_X,
        BAR_Y,
        BAR_W,
        BAR_H,
        SSD1306_WHITE);

    const int fillWidth =
        static_cast<int>(
            progress *
            (BAR_W - 4));

    if (fillWidth > 0)
    {
        display.fillRect(
            BAR_X + 2,
            BAR_Y + 2,
            fillWidth,
            BAR_H - 4,
            SSD1306_WHITE);
    }
}

// =====================================================
// Motor status screen
// =====================================================

void drawMotorScreen()
{
    display.clearDisplay();

    display.setTextColor(
        SSD1306_WHITE);

    display.setTextSize(1);

    // Header
    display.setCursor(0, 0);
    display.print("MACK-10 MOTOR TEST");

    display.drawFastHLine(
        0,
        10,
        SCREEN_WIDTH,
        SSD1306_WHITE);

    // Direction
    display.setCursor(0, 15);
    display.print("DIR: ");

    if (currentDirection == HIGH)
    {
        display.print("FORWARD");
    }
    else
    {
        display.print("REVERSE");
    }

    // Phase
    display.setCursor(0, 26);
    display.print(
        phaseName(motionPhase));

    // Step rate
    display.setCursor(0, 37);

    display.print(
        currentStepHz);

    display.print(" steps/s");

    // -----------------------------------------------
    // Progress through current phase
    // -----------------------------------------------

    float progress = 0.0f;

    const unsigned long elapsed =
        millis() - phaseStartMs;

    switch (motionPhase)
    {
    case ACCELERATING:
        progress =
            static_cast<float>(elapsed) /
            ACCEL_TIME_MS;
        break;

    case CRUISING:
        progress =
            static_cast<float>(elapsed) /
            CRUISE_TIME_MS;
        break;

    case DECELERATING:
        progress =
            static_cast<float>(elapsed) /
            DECEL_TIME_MS;
        break;

    case PAUSED:
        progress =
            static_cast<float>(elapsed) /
            DIRECTION_PAUSE_MS;
        break;

    case COMPLETE:
        progress = 1.0f;
        break;

    default:
        progress = 0.0f;
        break;
    }

    drawProgressBar(progress);

    display.display();
}

// =====================================================
// Startup display
// =====================================================

void drawStartupScreen(int seconds)
{
    display.clearDisplay();

    display.setTextColor(
        SSD1306_WHITE);

    display.setTextSize(1);

    display.setCursor(40, 8);
    display.println("MACK-10");

    display.setCursor(12, 25);
    display.println("SMOOTH MOTOR TEST");

    display.setTextSize(2);

    display.setCursor(58, 43);
    display.print(seconds);

    display.display();
}

// =====================================================
// Motion phases
// =====================================================

void beginAcceleration()
{
    motionPhase =
        ACCELERATING;

    phaseStartMs =
        millis();

    lastRampUpdateMs =
        millis();

    startStepGenerator(
        START_STEP_HZ);

    Serial.println(
        "Accelerating...");
}

void beginCruise()
{
    motionPhase =
        CRUISING;

    phaseStartMs =
        millis();

    changeStepFrequency(
        MAX_STEP_HZ);

    Serial.println(
        "Full speed.");
}

void beginDeceleration()
{
    motionPhase =
        DECELERATING;

    phaseStartMs =
        millis();

    lastRampUpdateMs =
        millis();

    Serial.println(
        "Decelerating...");
}

void beginPause()
{
    stopStepGenerator();

    motionPhase =
        PAUSED;

    phaseStartMs =
        millis();

    Serial.println(
        "Paused.");
}

// =====================================================
// Motion update
// =====================================================

void updateMotion()
{
    const unsigned long now =
        millis();

    const unsigned long elapsed =
        now - phaseStartMs;

    // ===================================================
    // Acceleration
    // ===================================================

    if (motionPhase ==
        ACCELERATING)
    {
        if (elapsed >=
            ACCEL_TIME_MS)
        {
            beginCruise();
            return;
        }

        if (now -
                lastRampUpdateMs >=
            RAMP_UPDATE_INTERVAL_MS)
        {
            lastRampUpdateMs =
                now;

            const float progress =
                static_cast<float>(elapsed) /
                ACCEL_TIME_MS;

            const int frequency =
                START_STEP_HZ +
                static_cast<int>(
                    progress *
                    (MAX_STEP_HZ -
                     START_STEP_HZ));

            changeStepFrequency(
                frequency);
        }

        return;
    }

    // ===================================================
    // Cruise
    // ===================================================

    if (motionPhase ==
        CRUISING)
    {
        if (elapsed >=
            CRUISE_TIME_MS)
        {
            beginDeceleration();
        }

        return;
    }

    // ===================================================
    // Deceleration
    // ===================================================

    if (motionPhase ==
        DECELERATING)
    {
        if (elapsed >=
            DECEL_TIME_MS)
        {
            beginPause();
            return;
        }

        if (now -
                lastRampUpdateMs >=
            RAMP_UPDATE_INTERVAL_MS)
        {
            lastRampUpdateMs =
                now;

            const float progress =
                static_cast<float>(elapsed) /
                DECEL_TIME_MS;

            const int frequency =
                MAX_STEP_HZ -
                static_cast<int>(
                    progress *
                    (MAX_STEP_HZ -
                     START_STEP_HZ));

            changeStepFrequency(
                frequency);
        }

        return;
    }
}

// =====================================================
// Run one direction
// =====================================================

void runDirection(bool direction)
{
    currentDirection =
        direction;

    // Stop STEP first before changing direction.
    stopStepGenerator();

    digitalWrite(
        DIR_PIN,
        direction);

    // Generous DIR setup time.
    delay(20);

    beginAcceleration();

    while (motionPhase != PAUSED)
    {
        updateMotion();

        // OLED is completely independent
        // of the STEP waveform now.
        if (millis() -
                lastDisplayMs >=
            DISPLAY_INTERVAL_MS)
        {
            lastDisplayMs =
                millis();

            drawMotorScreen();
        }

        // Give background ESP32 tasks time.
        delay(1);
    }

    drawMotorScreen();

    delay(
        DIRECTION_PAUSE_MS);
}

// =====================================================
// Setup
// =====================================================

void setup()
{
    Serial.begin(115200);

    delay(300);

    Serial.println();
    Serial.println("==============================");
    Serial.println(" MACK-10 SMOOTH MOTOR TEST");
    Serial.println("==============================");

    // ===================================================
    // GPIO
    // ===================================================

    pinMode(
        ENABLE_PIN,
        OUTPUT);

    pinMode(
        DIR_PIN,
        OUTPUT);

    pinMode(
        STEP_PIN,
        OUTPUT);

    // Safe startup states.
    digitalWrite(
        ENABLE_PIN,
        HIGH);

    digitalWrite(
        DIR_PIN,
        LOW);

    digitalWrite(
        STEP_PIN,
        LOW);

    // ===================================================
    // Hardware PWM / STEP generator
    // Arduino-ESP32 2.x API
    // ===================================================

    ledcSetup(
        STEP_CHANNEL,
        START_STEP_HZ,
        STEP_RESOLUTION_BITS);

    ledcAttachPin(
        STEP_PIN,
        STEP_CHANNEL);

    stopStepGenerator();

    // ===================================================
    // OLED
    // ===================================================

    Wire.begin(
        OLED_SDA_PIN,
        OLED_SCL_PIN);

    // SSD1306 generally supports 400 kHz I2C.
    Wire.setClock(
        400000);

    if (!display.begin(
            SSD1306_SWITCHCAPVCC,
            OLED_ADDRESS))
    {
        Serial.println(
            "OLED initialization failed.");

        while (true)
        {
            delay(1000);
        }
    }

    display.ssd1306_command(
        SSD1306_SETCONTRAST);

    display.ssd1306_command(
        0xFF);

    // ===================================================
    // Startup countdown
    // ===================================================

    for (int seconds = 3;
         seconds > 0;
         seconds--)
    {
        drawStartupScreen(
            seconds);

        delay(1000);
    }

    // ===================================================
    // Enable TMC2208
    // ===================================================

    digitalWrite(
        ENABLE_PIN,
        LOW);

    Serial.println(
        "TMC2208 enabled.");

    delay(500);

    // ===================================================
    // Forward
    // ===================================================

    Serial.println();
    Serial.println(
        "FORWARD");

    runDirection(
        HIGH);

    // ===================================================
    // Reverse
    // ===================================================

    Serial.println();
    Serial.println(
        "REVERSE");

    runDirection(
        LOW);

    // ===================================================
    // Complete
    // ===================================================

    stopStepGenerator();

    digitalWrite(
        ENABLE_PIN,
        HIGH);

    motionPhase =
        COMPLETE;

    phaseStartMs =
        millis();

    drawMotorScreen();

    Serial.println();
    Serial.println(
        "TEST COMPLETE");
}

// =====================================================
// Loop
// =====================================================

void loop()
{
    // One-shot test.
}

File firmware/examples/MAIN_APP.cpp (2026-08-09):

#include <Adafruit_GFX.h>
#include <Adafruit_SSD1306.h>
#include <Arduino.h>
#include <Wire.h>

#include "HX711.h"

// =====================================================
// Pins
// =====================================================

constexpr int HX711_DT_PIN = 21;
constexpr int HX711_SCK_PIN = 22;

constexpr int OLED_SDA_PIN = 32;
constexpr int OLED_SCL_PIN = 33;

// J6 pin 4 -> SELECT -> GPIO14
constexpr int SELECT_BUTTON_PIN = 14;

constexpr int STATUS_LED_PIN = 4;

// =====================================================
// Demo timing
// =====================================================

constexpr unsigned long AUTO_START_DELAY_MS = 5000;
constexpr unsigned long BREAK_SCREEN_DELAY_MS = 5000;

unsigned long menuStartMs = 0;
unsigned long breakDetectedMs = 0;

// =====================================================
// Dog animation timing
// =====================================================

unsigned long lastDogFrameMs = 0;
constexpr unsigned long DOG_FRAME_INTERVAL_MS = 250;

bool dogFrame = false;

// =====================================================
// Status LED pulse
// =====================================================

int statusBrightness = 5;
int statusFadeAmount = 2;

unsigned long lastStatusFadeMs = 0;

constexpr unsigned long STATUS_FADE_INTERVAL_MS = 15;

// =====================================================
// OLED
// =====================================================

constexpr int SCREEN_WIDTH = 128;
constexpr int SCREEN_HEIGHT = 64;

constexpr uint8_t OLED_ADDRESS = 0x3C;

Adafruit_SSD1306 display(
    SCREEN_WIDTH,
    SCREEN_HEIGHT,
    &Wire,
    -1);

// =====================================================
// HX711
// =====================================================

HX711 scale;

// TEMPORARY demo calibration.
// Replace this after real load-cell calibration.
constexpr float DEMO_COUNTS_PER_NEWTON = 500.0f;

// Demo break threshold in either direction.
constexpr float BREAK_THRESHOLD_N = 50.0f;

// Ignore tiny unloaded fluctuations around zero.
constexpr float ZERO_DEADBAND_N = 0.15f;

// =====================================================
// General timing
// =====================================================

unsigned long lastSerialPrintMs = 0;

constexpr unsigned long SERIAL_PRINT_INTERVAL_MS = 100;

unsigned long lastDisplayUpdateMs = 0;

constexpr unsigned long DISPLAY_UPDATE_INTERVAL_MS = 100;

// =====================================================
// Machine state
// =====================================================

enum MachineState
{
  MENU,
  TEST_RUNNING,
  BREAK_DETECTED
};

MachineState machineState = MENU;

// =====================================================
// Test display mode
// =====================================================

enum TestDisplayMode
{
  GAUGE_VIEW,
  GRAPH_VIEW
};

TestDisplayMode testDisplayMode = GAUGE_VIEW;

// =====================================================
// Force data
// =====================================================

long zeroOffset = 0;

float forceN = 0.0f;
float peakForceN = 0.0f;
float breakForceN = 0.0f;

// =====================================================
// Graph history
// =====================================================

// 120 samples x 100 ms = about 12 seconds on screen.
constexpr int GRAPH_HISTORY_SIZE = 120;

float forceHistory[GRAPH_HISTORY_SIZE];

// =====================================================
// Graph smoothing
// =====================================================

// 5 samples x 100 ms = about 0.5 sec moving average.
constexpr int GRAPH_SMOOTHING_SAMPLES = 5;

float smoothingBuffer[GRAPH_SMOOTHING_SAMPLES] = {0};

int smoothingIndex = 0;
int smoothingCount = 0;

// =====================================================
// Button debounce
// =====================================================

bool previousRawButton = HIGH;
bool stableButtonState = HIGH;

unsigned long lastButtonChangeMs = 0;

constexpr unsigned long DEBOUNCE_MS = 40;

// =====================================================
// Status LED
// =====================================================

void statusLedOn()
{
  digitalWrite(STATUS_LED_PIN, HIGH);
}

void statusLedOff()
{
  digitalWrite(STATUS_LED_PIN, LOW);
}

void statusLedBlink(int times, int delayMs)
{
  for (int i = 0; i < times; i++)
  {
    statusLedOn();
    delay(delayMs);

    statusLedOff();
    delay(delayMs);
  }
}

void resetStatusPulse()
{
  statusBrightness = 5;
  statusFadeAmount = 2;

  lastStatusFadeMs = millis();

  analogWrite(
      STATUS_LED_PIN,
      statusBrightness);
}

void updateStatusPulse()
{
  if (millis() - lastStatusFadeMs <
      STATUS_FADE_INTERVAL_MS)
  {
    return;
  }

  lastStatusFadeMs = millis();

  statusBrightness += statusFadeAmount;

  if (statusBrightness >= 100)
  {
    statusBrightness = 100;
    statusFadeAmount = -2;
  }
  else if (statusBrightness <= 5)
  {
    statusBrightness = 5;
    statusFadeAmount = 2;
  }

  analogWrite(
      STATUS_LED_PIN,
      statusBrightness);
}

// =====================================================
// Button handling
// =====================================================

bool selectPressed()
{
  const bool rawButton =
      digitalRead(SELECT_BUTTON_PIN);

  if (rawButton != previousRawButton)
  {
    previousRawButton = rawButton;
    lastButtonChangeMs = millis();
  }

  if (millis() - lastButtonChangeMs >=
      DEBOUNCE_MS)
  {
    if (rawButton != stableButtonState)
    {
      stableButtonState = rawButton;

      if (stableButtonState == LOW)
      {
        return true;
      }
    }
  }

  return false;
}

// =====================================================
// Graph history
// =====================================================

void clearForceHistory()
{
  for (int i = 0;
       i < GRAPH_HISTORY_SIZE;
       i++)
  {
    forceHistory[i] = 0.0f;
  }
}

void addForceHistory(float value)
{
  // Shift everything left one pixel/sample.
  for (int i = 0;
       i < GRAPH_HISTORY_SIZE - 1;
       i++)
  {
    forceHistory[i] =
        forceHistory[i + 1];
  }

  // Newest sample enters from the right.
  forceHistory[GRAPH_HISTORY_SIZE - 1] =
      value;
}

// =====================================================
// Graph smoothing
// =====================================================

float smoothGraphForce(float newValue)
{
  smoothingBuffer[smoothingIndex] =
      newValue;

  smoothingIndex =
      (smoothingIndex + 1) %
      GRAPH_SMOOTHING_SAMPLES;

  if (smoothingCount <
      GRAPH_SMOOTHING_SAMPLES)
  {
    smoothingCount++;
  }

  float total = 0.0f;

  for (int i = 0;
       i < smoothingCount;
       i++)
  {
    total += smoothingBuffer[i];
  }

  return total / smoothingCount;
}

void resetGraphSmoothing()
{
  for (int i = 0;
       i < GRAPH_SMOOTHING_SAMPLES;
       i++)
  {
    smoothingBuffer[i] = 0.0f;
  }

  smoothingIndex = 0;
  smoothingCount = 0;
}
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

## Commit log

2026-07-17 Restructure directory for firmware and electronics
    [MACK10_Controller.kicad_pcb, MACK10_Controller.kicad_sch]
2026-07-17 Added KiCad and Electronics Files
    [MACK10_Controller.kicad_sch]
2026-07-17 Initial PCB Layout
    [MACK10_Controller.kicad_pcb, MACK10_Controller.kicad_sch]
2026-07-18 Update PCB Layout
    [MACK10_Controller.kicad_pcb, MACK10_Controller.kicad_sch]
2026-07-18 Various PCB Updates
    [MACK10_Controller.csv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]
2026-07-19 Minor PCB Updates
    [MACK10_Controller.kicad_pcb]
2026-07-20 Various PSB and Schematic Updates
    [MACK10_Controller.kicad_pcb, MACK10_Controller.kicad_sch]
2026-07-23 Add Todo and various PCB updates
    [MACK10_Controller.kicad_pcb, MACK10_Controller.kicad_sch]
2026-07-23 Various PCB and Schematic Updates
    [MACK10_Controller.kicad_pcb, MACK10_Controller.kicad_sch]
2026-07-23 PCB Traces Completed - First Run
    [MACK10_Controller.kicad_pcb, MACK10_Controller.kicad_sch]
2026-07-23 Finalize V1 PCB Layout
    [MACK10_Controller.kicad_pcb]
2026-07-26 RevA PCB Layout Finalized
    [MACK10_Controller-B_Cu.gbl, MACK10_Controller-B_Mask.gbs, MACK10_Controller-B_Paste.gbp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]
2026-07-27 Local sync
    [MACK10_Controller.kicad_pcb]
2026-07-30 V2 Updates and File Structure Changes
    [MACK10_Controller-B_Cu.gbl, MACK10_Controller-B_Mask.gbs, MACK10_Controller-B_Paste.gbp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]
2026-08-03 PCB Updates
2026-08-07 V1 Board Testing, PCB and Script Updates
2026-08-09 Motor control testing
2026-08-10 Update Project Task List
    [MACK10_Controller.kicad_pcb]
2026-08-14 Readme Project and BOM Updates
2026-08-26 Various V2 PCB Schematic Changes
    [XIAO_ESP32C6_Pinout (1).xlsx, condensed_board_v2.kicad_sch]
2026-08-27 Various PCB Schematic Updates
    [MACK10_V1_Controller.kicad_sch, condensed_board_v2.kicad_sch, unused_schematic_blocks.kicad_sch]
2026-08-27 Minor PCB Changes
    [condensed_board_v2.kicad_sch]
2026-08-27 Updated Footprints and ERCs Passed
    [MACK10_Controller.csv, MACK10_Controller_V1_Backup.kicad_pcb, MACK10_Controller_V1_Layout.kicad_pcb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]
2026-08-28 First pass of PCB Layout (front and back)
    [MACK10_Controller.kicad_pcb, condensed_board_v2.kicad_sch]
2026-08-29 PCB Layout Finalization
    [MACK10_Controller.kicad_pcb, condensed_board_v2.kicad_sch]
2026-08-30 Netclass and Via Updates
    [MACK10_Controller.kicad_pcb]
2026-08-30 More Traces
    [MACK10_Controller.kicad_pcb]
2026-08-30 Majority of traces done
    [MACK10_Controller.kicad_pcb]
2026-08-30 DRC Cleanup - Zero Violations
    [MACK10_Controller.kicad_pcb]
2026-08-30 Resolved DRC warnings, fixed thermal reliefs and clearance issues, rerouted some traces.
    [MACK10_Controller.kicad_pcb]
2026-08-30 Added EN for reboot, finishing touches
    [MACK10_Controller.kicad_pcb, condensed_board_v2.kicad_sch]
2026-08-31 All Checks Passed - V2 Sent for Manufacture
    [BOM1.csv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]
2026-08-31 Documentation Updates
    [MACK10_Controller.kicad_pcb]
2026-09-21 Various Updates
    [MACK10_Controller.csv]
